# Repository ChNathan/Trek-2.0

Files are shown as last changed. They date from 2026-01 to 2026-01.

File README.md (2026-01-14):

# Trek-2.0
Project report and files for Oslo Met EPS project. We built a gait tracker for real time gait asymmetry over varying windows.

Included in this Repo Are:
- Trek EPS Report ( Which is covered in additional detail via this presentation https://docs.google.com/presentation/d/1eJzCRBbl3npr1pbE6kb9zn8NsA4ln3SlZraTO1EqVzs/edit?usp=sharing )
  - This report includes the project's purpose, progress, and future recommendations. We believe this project could be piloted in research studies with an additional project iteration.
- Firmware Code for Left and Right device, with and without SD Card
- User Interface Code
- Short user manual on setting up the device
- Autodesk Invetor CAD File for Case
- KiCad PCB Schematics, BOM, and additional design files

For any questions, comments, or concerns, please don't hestitate to contact us.
- Group 1, EPS Fall 2025


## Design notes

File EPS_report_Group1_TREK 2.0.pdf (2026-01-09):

## Oslo Metropolitan University

# TREK 2.0 :

# Bilateral Gait Monitoring System

image generated by AI
Completed by:
Chethan James Magnan,
Jeyapiriyan Thevaranjan,
Thomas Druillole,
Luke ten Klooster,
Michael Prediger,
Fall 2025

Mentored by:
Tom Muir
Tengel Aas Sandtrø

Supervised by:
Dr. Ali Muhrtagolu
Dr. Haroon Khan

European Project Semester

## Table of Contents

Table of Contents | 2
1. Introduction | 3
1.1. Project context | 3
1.2. Project objectives and relevance | 3
2. Scientific and Technical Background | 4
2.1. Fundamental concepts and key definitions | 4
2.2. Overview of existing methods and techniques | 5
2.3. Relevance to our project | 7
3. Review of Previous Work | 8
3.1. Previous Trek device | 8
3.2. Strengths of previous device | 9
3.3. Limitations | 9
3.4. Improvement and development strategy | 10
4. Project Management and Task Organization | 11
4.1. Mission Goals Scope (MGS) | 11
4.2. Project organization and planning | 12
4.3. Communication and collaboration | 13
5. System Architecture | 14
5.1. Hardware design and architecture | 14
5.2. System logical architecture | 15
5.2. Embedded firmware | 16
6. Implementation | 18
6.1. PCB design and hardware design | 18
6.2. Mechanical and 3D design | 20
6.2.1. Manufacturing methods | 20
6.2.2. Material selection | 21
6.2.2. 3D Design | 23
6.3. Signal processing and algorithm development | 25
6.3.1. Data acquisition | 25
6.3.2. Gait State Analysis | 26
6.3.3. Position estimations and stride length calculations | 31
6.4. Wireless communication | 33
6.4.1. Importance of wireless communication | 33
6.4.2. Choice of Bluetooth Low Energy (BLE) over Wi-Fi | 33
6.4.3. How Bluetooth Works in the System | 34
6.5. User Interface design and application development | 35
6.6. Integration and system validation | 37
7. Conclusion | 38
7.1. Project conclusions and key findings | 38
7.2. Skills acquired | 38
7.3. Reflections and overall experience | 39
8. References | 42
9. Appendix | 45

## 1. Introduction

## 1.1. Project context

As of 2010, there were 1.6 million people suffering from hip fractures, with 600,000 in Europe alone [1]. This number is expected to rise, with researchers predicting 6 million hip fractures annually by 2050 [2]. For the average person, the process seems straightforward: they go to the hospital, the surgery is successful, and all is well. However, about 40 to 60% of patients never fully regain their previous activity levels, experiencing declining mobility in daily life [2]. The cause is often musculoskeletal impairment following a hip fracture (sarcopenia) and an asymmetric gait, where steps do not align during walking [3]. Without frequent monitoring, this condition tends to progress, leading to slower walking, more frequent falls, and overall deterioration in quality of life. Because this decline occurs gradually and recovery feedback is delayed, many patients do not adhere to physical therapy or notice improvements. Improved monitoring and timely feedback from healthcare professionals could help these patients recover daily function more effectively [4].

## 1.2. Project objectives and relevance

For patients recovering from musculoskeletal impairments, measuring gait asymmetry is essential to track recovery and prevent physical deterioration before it becomes severe. The device must be easy to use, non-intrusive in daily life, and provide actionable information. Some solutions exist on the market but do not fully address our use case: supporting older adults in a physical therapy context to recover daily function. Some devices, like the MbientLab MMRL [5], are affordable but provide only raw sensor data, which can overwhelm non-technical users. Others, such as the Movella Xsens Awinda [6], are designed for highly specific clinical research applications, relying on a distributed sensor grid within a controlled environment and are prohibitively expensive, with purchase details handled directly via sales teams. Neither solution allows continuous, real-time gait analysis throughout the day.

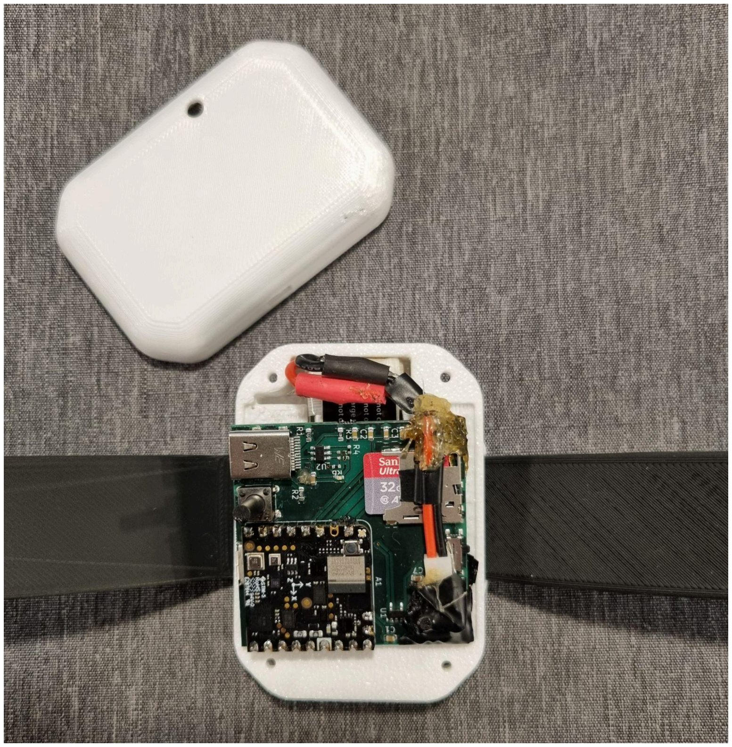
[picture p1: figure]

Figure 1.1 : Trek 2.0

Our project, Trek 2.0, is a compact wearable device designed to monitor walking patterns, building upon the prototype developed by the previous group. It enables patients and healthcare professionals to track gait asymmetry between the left and right legs in real time, providing insights to prevent long-term joint and muscle deterioration. The device is intended for use in physical therapy, offering continuous, easy-to-use, and non-intrusive gait monitoring to support recovery and improve daily function.

## 2. Scientific and Technical Background

This section starts by defining key concepts and providing an overview of the general research conducted in this area. This provides context, making it easier to understand the work of previous groups as well as our own development. More specific research and detailed studies can be found in their corresponding sections to maintain a clear and engaging flow.

## 2.1.Fundamental concepts and key definitions

General gait concepts :
Gait refers to the coordinated pattern of walking, describing how the legs and feet move during locomotion [7].

Gait assessment, also known as gait analysis, is the process of measuring and evaluating this walking pattern, typically using sensors such as inertial measurement units (IMUs) to quantify spatial, temporal, and symmetry-related parameters.

A gait cycle is defined as the interval between two consecutive heel strikes of the same foot, representing a complete sequence of movements that can be analyzed to extract relevant gait parameters. The different phases of the gait cycle are discussed in Section 6.3.2.

A gait event refers to a specific, identifiable moment within the gait cycle, such as a heel strike or toe-off. These events are key reference points for analyzing gait parameters, detecting asymmetries, and calculating stride and step characteristics.

Bilateral gait measurements refer to the simultaneous assessment of both legs, allowing for the evaluation of asymmetries and coordination between left and right limbs. These measurements are critical for understanding differences in gait patterns, detecting abnormalities, and improving the accuracy of gait analysis.

Stride length - definition and clinical relevance :

Figure 2.1 : Illustration of spatial parameters of gait

Stride length is a key gait parameter, defined as the distance covered by the foot during a single gait cycle. It is particularly relevant because it provides several advantages: it directly reflects walking efficiency and step consistency, offering a clear and interpretable measure of gait performance [8]. Furthermore, it can be tracked over time to assess changes or improvements in patients.

Stride length is sensitive to gait abnormalities and asymmetries, making it a valuable indicator for clinical assessment and rehabilitation. Studies conducted by Umeå University (Sweden), the University Clinical Centre of Kosovo, and St George’s University (UK) have shown that stride length is strongly associated with clinical outcomes such as disability and mortality [8]. According to Wang and Bhatt (University of Illinois at Chicago), individuals with a history of falls exhibited shorter stride lengths and significant asymmetries, highlighting the potential of stride length monitoring in fall prevention [9].

Stride length can also be compared across individuals by normalizing it to patient height (normalized stride length = stride length (cm) / height (cm)). For instance, Bytyçi and Henein (2021) reported that this normalized stride length was more accurate in predicting adverse clinical events, with a summary sensitivity of 65%, specificity of 72%, and overall accuracy of 75.5% [8].

Other gait parameters, including stride time and cycle time, are presented in Section 6.3, where their calculation and use in deriving additional gait metrics are detailed.

## 2.2. Overview of existing methods and techniques

Several studies and projects have explored the use of inertial measurement units (IMUs) for gait analysis. These works provide insights relevant to the development of wearable gait monitoring systems.

IMU-based gait assessment and bilateral coordination:

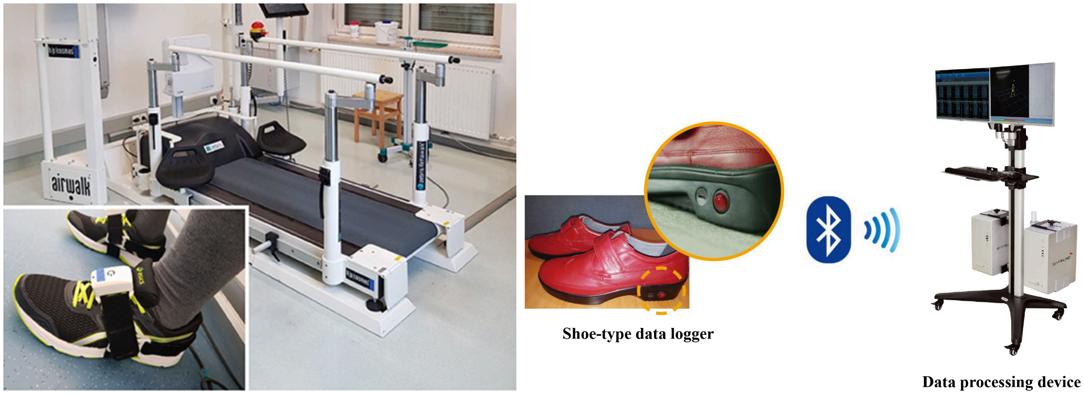
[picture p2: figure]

Figure 2.2 : Experimental setups from similar studies. Left: Laidig et al. (2021) – patient with foot-mounted IMUs and instrumented treadmill. Right: Han et al. (2019) – shoe-type IMU-based gait analysis system.

Laidig et al. (2021) [10] and Han et al. (2019) [11] demonstrated methods for assessing gait parameters using IMU sensors. Laidig et al. focused on foot-mounted sensors and calibration-free measurement of gait pattern, speed, rhythm, and step coordination, while Han et al. analyzed bilateral coordination and gait asymmetry with shoe-mounted sensors.

Sensor placement considerations:
Küderle et al. (2022) [12] and Panebianco et al. (2018) [13] investigated how sensor position affects measurement accuracy and reliability. Küderle et al. showed that different foot-mounted IMU placements strongly influence spatial parameter accuracy. Mean stride-length errors remained below 2 cm for most positions, while poorly located sensors, such as the heel, produced occasional single-stride errors up to ~60 cm, highlighting the importance of proper placement.

Figure 2.3 : Panebianco et al. (2018) – Sensor placement of the six shoe-mounted IMUs.

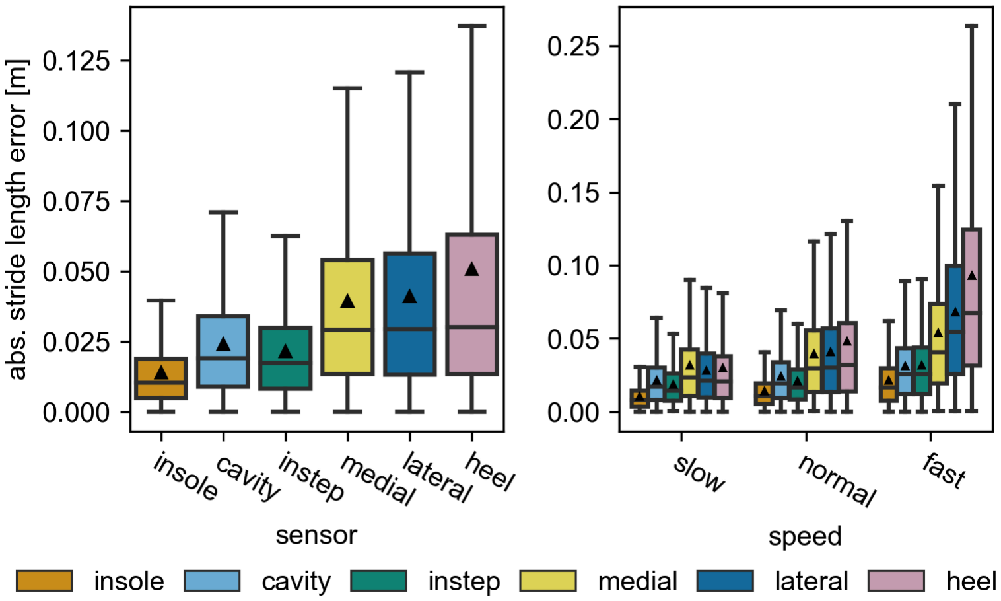
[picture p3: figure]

Figure 2.4 : Panebianco et al. (2018) – The absolute stride length error of each sensor position.

Panebianco et al. confirmed that sensor position significantly affects measurement repeatability, as shown in Figure 2.4, which illustrates the absolute stride-length error for each sensor position.

Gait event detection algorithms:
Panebianco et al. (2018) [13] evaluated 17 different algorithms for detecting gait events and estimating temporal gait parameters from IMU data. Their results showed that shank- and foot-based algorithms were more accurate and repeatable than lower-trunk-based approaches for detecting heel strikes and toe-offs. Angular velocity-based methods outperformed acceleration-based ones for these events, providing more reliable measurements.

Gait symmetry and coordination insights:
Błażkiewicz et al. (2014) [14] and Gimmon et al. (2018) [15] focused on gait symmetry and coordination. Błażkiewicz et al. compared methods for quantifying left-right differences, while Gimmon et al. studied changes in bilateral coordination with age, using the phase coordination index and gait asymmetry metrics. These works provide guidance for selecting symmetry metrics and interpreting variations across different populations.

## 2.3. Relevance to our project

The reviewed studies provide practical guidance for the development of our wearable gait monitoring system. Although Laidig et al. [10] and Han et al. [11] focused on foot- and shoe-mounted sensors, resulting in data different from ours, which uses lower-limb bracelets, these studies can serve as benchmarks to help interpret sensor signals and guide the measurement of gait parameters. They also provide a useful comparison for evaluating our final gait measurements.

Küderle et al. [12] and Panebianco et al. [13] emphasize the critical role of sensor placement and algorithm selection in ensuring measurement accuracy and repeatability. Insights from these studies support our choice of bracelet position. They can also guide algorithmic decisions for detecting gait events such as heel strikes and toe-offs.

Błażkiewicz et al. [14] and Gimmon et al. [15] are relevant to the project because it involves calculating differences between the left and right foot during walking. Błażkiewicz et al. provide guidance on selecting appropriate gait symmetry coefficients to quantify these differences, while Gimmon et al. show how bilateral coordination and gait symmetry vary with age. Understanding these variations helps interpret IMU sensor data accurately and assess gait differences across different populations.

## 3. Review of Previous Work

## 3.1. Previous Trek device

This project is a continuation of the previous Trek device, which presents both advantages and challenges for development.

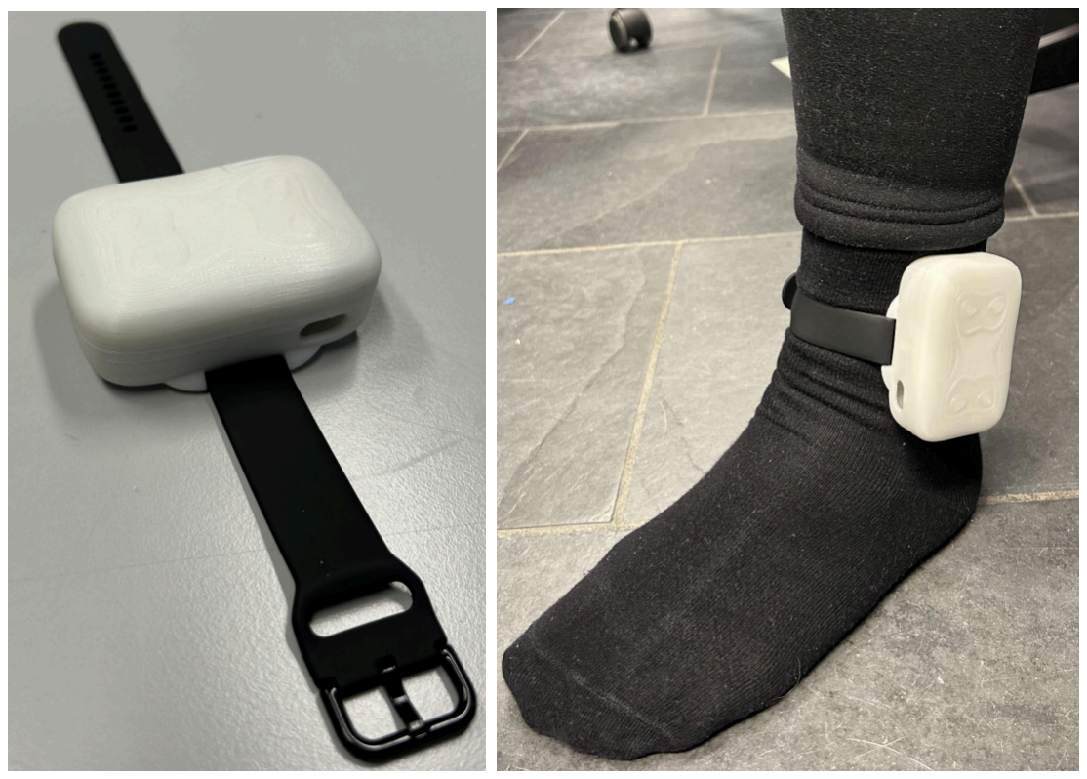
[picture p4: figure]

Figure 3.1 : Final prototype of the previous Trek device [16]

The previous Trek device is a proto-board with an IMU, (Inertial Measurement Unit), BLE transmitter and receiver (Bluetooth Low Energy), MicroSD Card, charging port, and power switch. This device takes accelerometer, gyroscope, and magnetometer data and saves this to a MicroSD card. The data can then be uploaded offline into an accompanying MATLAB script to calculate and generate a plot for the asymmetries between each leg.

Due to the existence of the previous product, we should be able to achieve more and better address the clients’ needs. We were starting with the basic circuitry, programming, mobile communication, and classification algorithms from the previous group. This would mean we could focus on optimization and expansion.

## 3.2. Strengths of previous device

The previous Trek device is the first step forward and accomplished what they set out to do -the device has a completed data path, the overall device physically worked. It is an end to end device, able to receive input from the Nicla, send these over the soldered wires for storage in a MicroSD card, and then output a useful gait asymmetry calculation with graph.

The main functional units were logically decided and purchased with off the shelf components to make the prototype work as predicted for the final use case. Finally, the previous team did use Github sharing how they had structured the arduino measurements and left a report detailing their project planning, execution, and suggestions for the future. This report was particularly useful as it allowed us to understand how they thought through their device, recreate the overall circuitry as photos covered how the device was wired, and have a very clear goal.

## 3.3.Limitations

There are three main areas for improvement based on the deliverables we received from the previous Trek group :
- Real-time asymmetry calibration was not possible. The device stored data on the SD card, and asymmetry values were computed offline in MATLAB. This prevented immediate feedback for the user.
- The device did not include any user interface. As a result, patients could not adjust their walking based on real-time feedback, and sharing data with a clinician was inconvenient. Without an interface, a medical professional could not easily compare changes in daily mobility, identify whether physical decline had slowed, or evaluate how gait evolved throughout the day.
- The device was too large. A more compact design was requested to improve usability and reduce manufacturing cost. Smaller devices are also better accepted by older adults. This is supported by recent long-term wearable research, which reports that “almost without exception, participants desired smaller and lighter wearables or expressed discontent about the size and weight of the device they were asked to wear in the study” [17].

## 3.4. Improvement and development strategy

The initial Trek device aims to solve this with a Goldilocks solution. The device is portable and customized to detect gait, but as we address in depth in the previous section, it is not real time, compact, nor have a ui device and therefore still in a prototype phase. Our further developments to the Trek device aims to make it a professional gait-tracking tool. We want it to be used for assisting in physical therapy, where professionals may monitor patient walking patterns in real time to prevent long-term joint and muscle damage.

With this objective, we defined three main development directions: creating a mobile interface, enabling real-time IMU data transmission, and reducing the device size and weight.

Achieving real-time communication requires redesigning the wireless data flow and reworking the embedded signal processing. To reduce energy consumption and extend battery life (thus allowing a smaller battery), most calculations must be performed directly on the embedded system, whereas the previous group relied on heavy MATLAB-based offline processing, which is not feasible on an embedded system.

We also plan to develop a custom circuit board, implement improved data batching to limit power draw, and design a new, thinner enclosure, so that we can reduce the overall footprint of the device and its size. This new design will also provide additional benefits in terms of manufacturing cost and component integration.

Figure 3.2 : Comparison image between TREK 2.0 (on the top) and TREK 1.0 (below)

## 4. Project Management and Task Organization

## 4.1. Mission Goals Scope (MGS)

Mission:
Trek is a clinical gait-tracking tool for physical therapy where professionals monitor patient walking patterns in real time to prevent long-term joint and muscle damage. Our mission is to enhance the system by improving user comfort, optimizing both hardware and software performance, and designing an intuitive interface that allows patients to monitor their gait in real time.

Goals:
Our main focus is completing the client’s request; make Trek real time, more compact, and have an improved user interface. For a functional TREK system capable of bilateral gait monitoring in real time we need system to turn on and send basic imu measurements via wireless communication

To make it lighter and compact (at least 20% smaller and weigh 20% less), we should have a custom circuit board design that is 20% smaller than previous as well as a case that’s 20% smaller by volume.

Finally, to improve the value of the user experience, we should make a mobile user interface that can assess and process the system in real time. This includes an adjustable window time scale to see a whole day of measurements.

Scopes:
Our main constraints are the previous group's work and the lack of clinical use case. We will not remake the project from the beginning and should reuse as much as possible from the previous group’s work, which means some of their decisions or technical debt must be considered.

This device is also not for a clinical use case at the moment. The intention is not for the product to be commercialized, nor diagnose medical problems, nor implement a user account management system. A commercialized product would need far more polishing and testing with user groups. To diagnose medical problems, we would want to work closer with medical professionals and need far more time and funding. Finally, as the group lacks a data specialist, the development of a digital database for the online interface will be omitted.

## 4.2. Project organization and planning

For the management part of our project, we wanted to ensure that the work is well organized and that every team member knows their responsibilities. Management therefore plays a key role in our team. During the research phase, we defined in detail the tasks required to complete the project. We grouped these tasks into five main study domains, each with clear objectives :
- Redesign circuit board: improve compactness, update components, and optimize embedded functionality.
- Redesign case: enhance ergonomics, adapt to the new materials and reduce size and weight.
- Sensor data processing: implement efficient algorithms for gait analysis in real-time.
- Wireless communication: enable real-time BLE data transfer between device and UI.
- User interface: develop a mobile interface for easy monitoring and feedback.

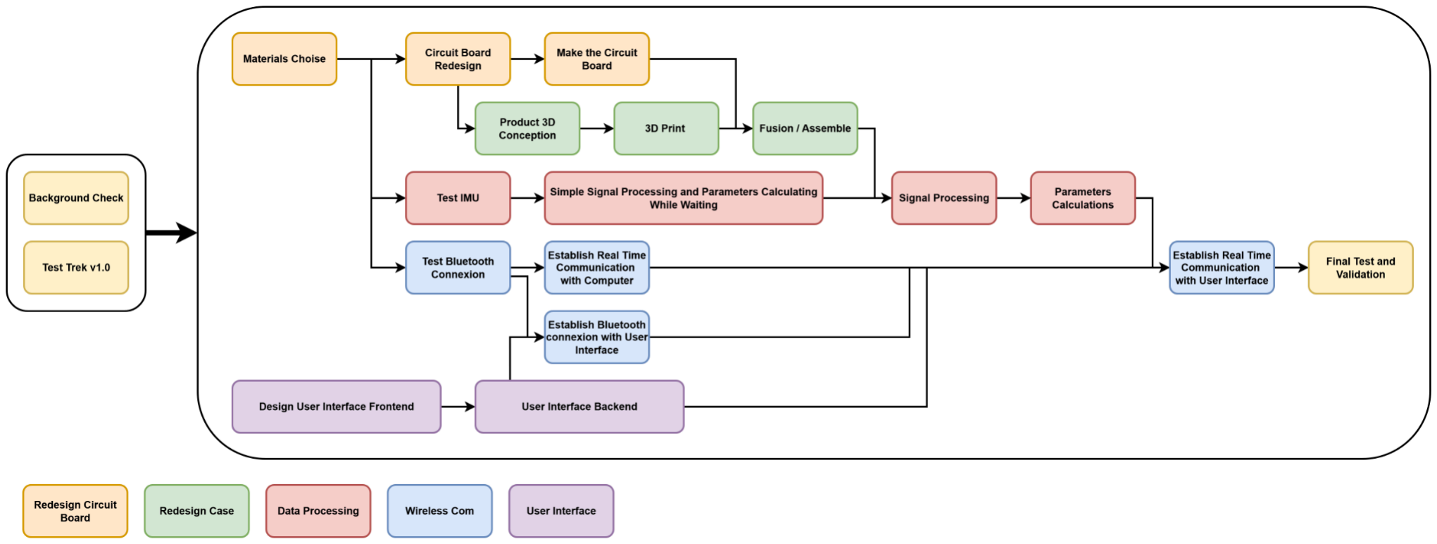
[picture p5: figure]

Figure 4.1 : simplification of the GANTT diagram

To manage the timeline, we created a detailed Gantt chart that helps us plan the various tasks, track progress, and identify deadlines (see appendix). We also prepared a simplified version of the Gantt chart (Figure 4.1) that groups the most important stages of our project. This version makes it easy to see the dependencies between stages.

To ensure the smooth progress of the project and clearly define each team member’s responsibilities, our team was organized around complementary areas of expertise. Each member took charge of specific aspects of the development, from mechanical design to software and embedded systems engineering, ensuring that all parts of the project were properly coordinated and progressed according to schedule.

- Chethan James Magnan – Computer Engineer: responsible for the circuit board redesign and communication with the supervisor.
- Jeyapiriyan Thevaranjan – Embedded Systems Engineer: focuses on embedded firmware development and manages the Gantt chart to keep the project on schedule.
- Thomas Druillole – Mechanical Engineer: handles Bluetooth real-time communication and backend support for the user interface.

- Luke ten Klooster – Mechanical Engineer: responsible for frontend and user experience.
- Michael Prediger – Mechanical Engineer: manages CAD design and prototyping of the case.

## 4.3. Communication and collaboration

To ensure effective communication and collaboration, our team relies on Microsoft Teams, WhatsApp, and GitHub. These tools allow us to share ideas quickly, centralize contributions, and maintain easy access to all project materials. GitHub is particularly useful for tracking changes in code and documentation, while Teams and WhatsApp facilitate fast discussions and coordination.

Although each team member has specific responsibilities as a team leader in their area, we work closely together rather than independently. Team leaders coordinate tasks, but all members are involved whenever needed, ensuring that progress is smooth and consistent across all areas.

Weekly meetings are held to review the work completed, discuss challenges, and plan tasks for the coming week. At the beginning of each meeting, members give a brief update on their progress. All discussions and task assignments are recorded in a shared document, which allows everyone to stay informed, follow the project’s progress, and adjust priorities if necessary.

This structured approach to communication and collaboration helps our team stay aligned, efficiently distribute the workload, and maintain high productivity throughout the project.

## 5. System Architecture

## 5.1. Hardware design and architecture

The systems hardware architecture organizes how power (via the battery and its USB C charging circuit ) will be supplied to the functional units of the Trek device ( the Arduino Nicla with its BLE and the MicroSD card ) as well as how the user will interact with the device ( the BLE on off button and the power switch ). This overall architecture is illustrated in the figure below. By optimizing the design for production, the cost is further reduced from approximately 130 EUR to 70 EUR. While the Arduino cost remains around 60 EUR, the price of the peripherals drops to roughly 15 EUR when manufactured in quantities of 1000.

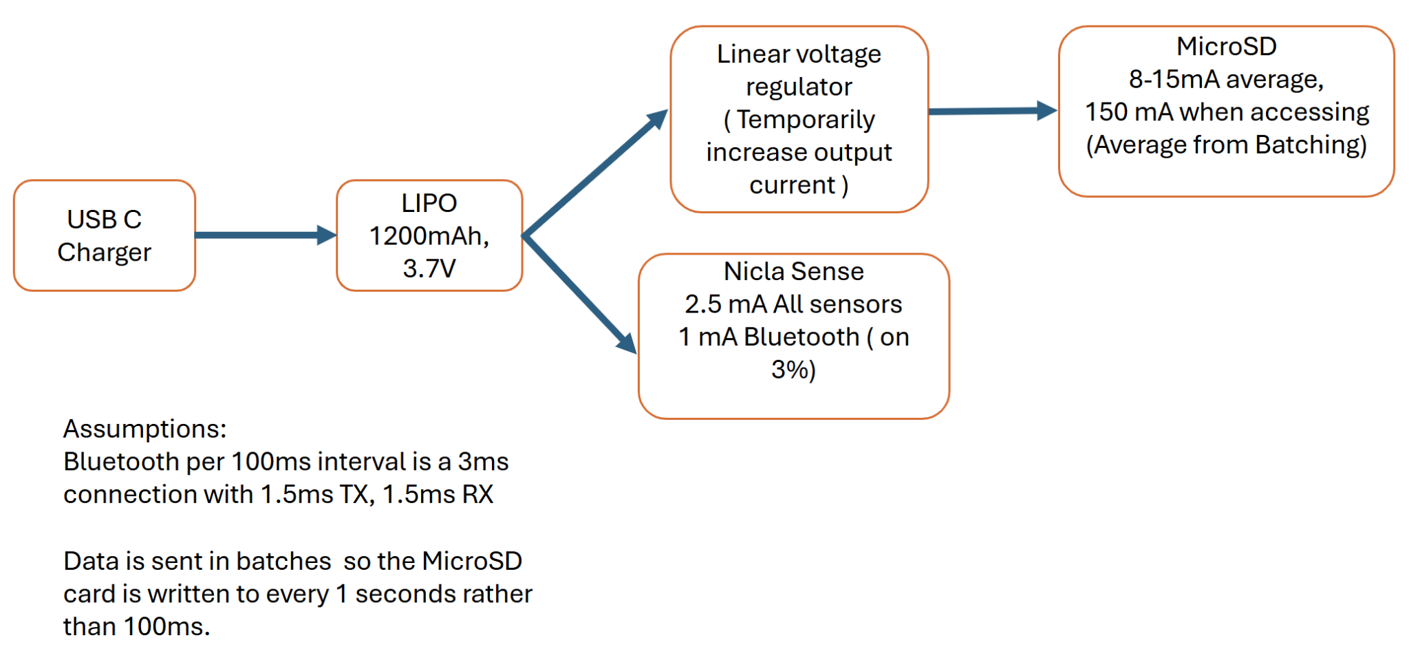
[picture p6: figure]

Figure 5.1 : Logical schema of the hardware architecture

The previous group used many of the same type of component and the overall structure is fairly similar. This was maintained to use the previous groups contributions as we agreed with their rationale - this component setup offers the main functionality such a device would require and met our clients requests.

The only major modifications to the circuit were; the BLE button, decreasing the distance between each component, and updating components that went out of stock. Decreasing the component distance makes the entire device more compact and leads to less noise. We achieved this through the design and outsourced manufacture of the Printed Circuit Board ( PCB ). Finally, some components were no longer offered by the suppliers and as such were updated with equivalent but more recent versions.

We also disagreed with the previous group's battery calculations and performed our own.By slightly reducing power consumption—primarily by decreasing the access interval to the MicroSD card (configured in the embedded firmware), we calculate that we can power the entire board per day on a minimum 3.7 V, 83 mAh, 307 mWH Lithium polymer (LiPo) battery.

For our design, we chose to use the 450 mAh 3.7v Utuav battery due to its thinner horizontal form and multiple day charge. This is again beneficial as it continues to make the design more compact for our end user when compared to previous 1200mAh LiPo. In terms of volume, the battery footprint decreases from 10.8 cm³ to 7.14 cm³ (a 34% reduction), and the surface area required inside the device decreases from 21.6 cm² to 10.2 cm² (a 53% reduction).

## 5.2. System logical architecture

Our TREK 2.0 system is built on a technical architecture that can be divided into three levels:

1) Data acquisition and real-time processing on the embedded board (Arduino Nicla Sense ME):
The embedded firmware continuously collects IMU data. These signals are processed with filtering methods to identify gait phases and spatial positions. Only the essential information—such as stride length and asymmetry—is extracted in order to reduce transmission load and optimize energy consumption.
2) Low-latency wireless transmission via Bluetooth Low Energy (BLE):
The processed data are sent to the interface through BLE in small, low-latency packets. In parallel, all raw and processed data are stored on the MicroSD card to ensure full backup even in case of disconnection, allowing the system to operate without requiring a permanent Bluetooth connection.
3) Real-time visualization and parameter display through the user interface:
The interface receives and decodes BLE packets in real time, updates its graphs, and recalculates parameters over the time window selected by the user. This enables continuous and instantaneous visualization of gait behaviour and asymmetry between both legs. The user can choose between a minimal mode (real-time essential information: stride length, asymmetry) or a debug mode (detailed analysis, not real-time).

Figure 5.3 : Logical schema of our device architecture

## 5.2. Embedded firmware

The Nicla Sense ME embedded in the bracelet must operate fully autonomously to ensure continuous gait monitoring under all conditions. For this reason, the system requires a robust embedded firmware capable of handling all operational scenarios without external intervention.

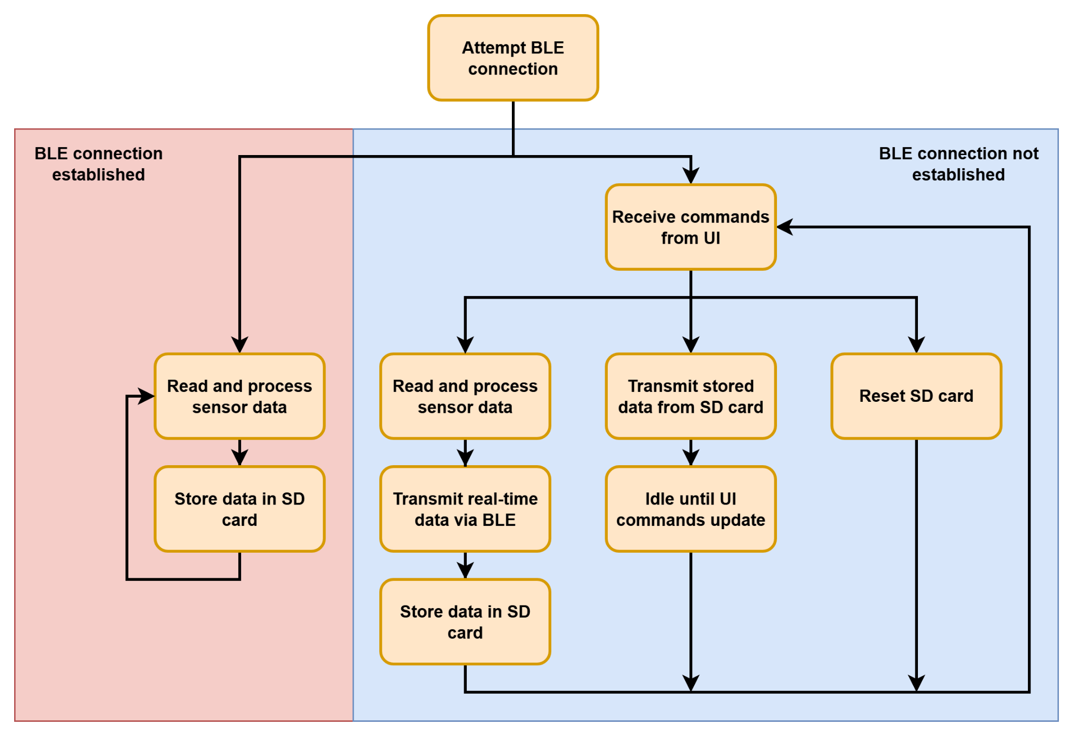
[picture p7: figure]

Figure 5.2 : embedded firmware architecture overview

Real-time communication is one of the major improvements compared to the previous group’s work. At startup, the firmware attempts to establish a Bluetooth connection with the user interface (UI) during a 20-second initialization window. Two operational modes are then possible:

- If the Bluetooth connection is not established within the allotted time : the system switches to standalone mode, where gait measurements are continuously acquired and stored locally on the MicroSD card.
- If the Bluetooth connection is successfully established : the firmware enters real-time streaming mode. Sensor data are transmitted live to the UI while simultaneously being logged on the MicroSD card to ensure that all data are saved.

In this mode, the board can also receive configurations from the UI, such as the selected operating ui-mode (section 6.5) and the data transmission frequency (section 6.5), allowing the user to adapt system behavior in real time.

Additionally, when the device receives the command to enter debug mode and the onboard button is pressed, all previously stored MicroSD-card data are transferred to the UI.To return to streaming mode, the ui-mode must be switched and the button pressed again.

This dual-mode architecture guarantees continuous gait data acquisition regardless of connectivity conditions.

## 6. Implementation

## 6.1. PCB design and hardware design

For the Printed Circuit Board (PCB) design and function, we used the existing circuit. Time constraints and Oslo Met's electronics lab dictated the scale and type of PCB. We did surface-mount full assembly with Eurocircuits, so the main focus was designing the PCBs and validating or modifying them based on tests.

The design process proceeded relatively smoothly, taking a few weeks to find the original parts used by the previous group. We chose to maintain the same PCB and general components to prevent any coding or peripheral communication errors. As most of our initial development was done using the Arduino Nicla given by the previous group, we kept using this as our main CPU / processing unit.

The PCB functions as a socket connecting the Arduino Nicla sense me and attaches the battery charger, battery pack, MicroSD card with reader, and two switches – a push button for choosing to access Bluetooth as a power saving feature and an SPDT power switch. The designs were done in Kicad, and some sampling from online schematics from Soldered Electronics was done (both are open source and available for our use case). The schematics, PCB layout, and 3D visualizations are included in the appendix.

Figure 6.1 : CAD of the PCB board

These designs were then reviewed and submitted to Eurocircuits for manufacture. After receiving 5 PCBs, a multimeter and power supply were used to confirm that there were no shorts in the circuit, that each functional unit worked appropriately, and that the PCB could receive and charge power from the lithium ion battery.

Some minor modifications were necessary: the button was rotated, the power connector needed to be modified to accommodate our battery’s connector, and a resistor needed to be removed that shorted the linear voltage converter for the USB-C charger. Once these modifications were complete, the PCB met the needs of the project in terms of battery life, support for real-time functionality, and size reduction.

The overall battery life matched the theoretical calculations. Real-time access to the MicroSD card is supported, and Bluetooth communication remains fully functional. Finally, the PCB footprint was reduced from 21.46 cm² to 17.22 cm², corresponding to a 19.8% reduction.

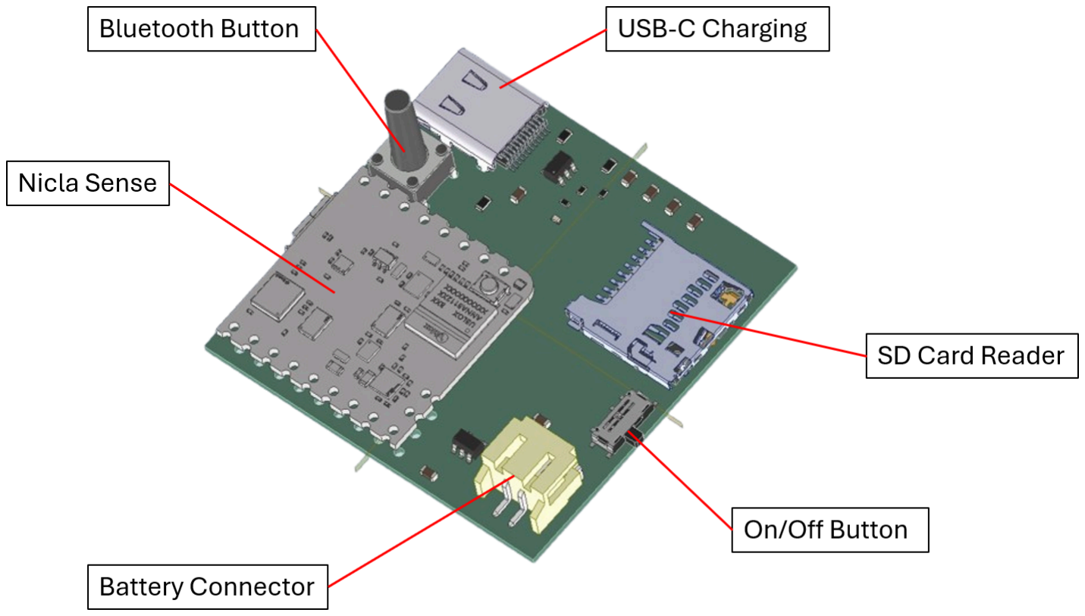
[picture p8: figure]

Figure 6.2 : CAD of the PCB with component labels

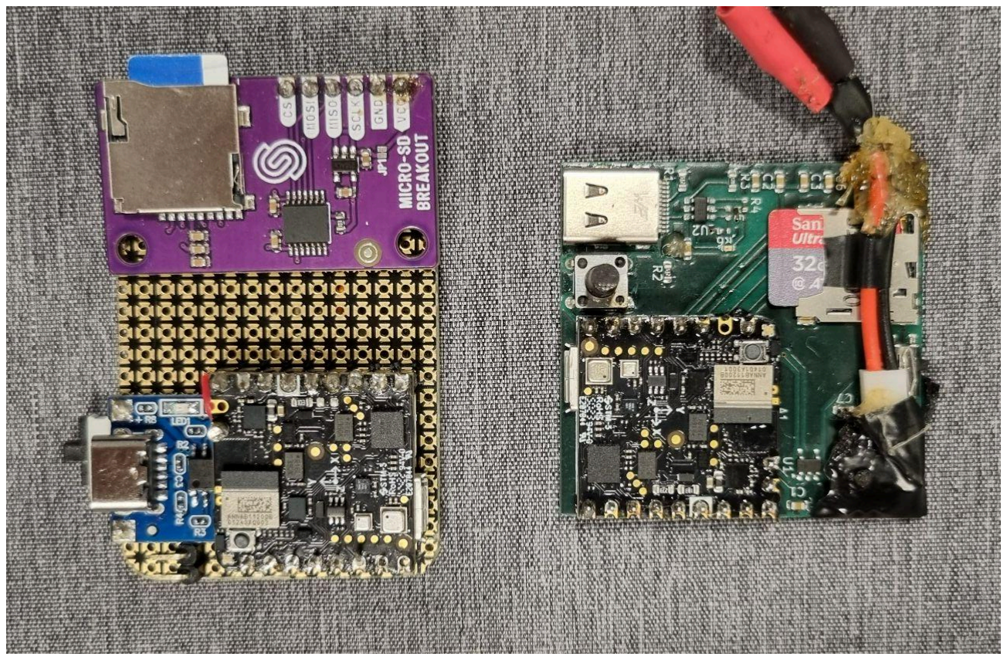
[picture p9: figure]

Figure 6.3 : Previous board (left) compared to our PCB (right)

## 6.2. Mechanical and 3D design

This part of the report outlines the development process of the 3D model and the manufacturing of the prototypes. The focus of this work was the design of a new case that securely positions all internal components while improving overall usability. Compared to the device created by the previous group, our prototype aims to offer enhanced wearing comfort. The goal was to create a compact and lightweight design that provides mechanical stability.

6.2.1. Manufacturing methods
Before selecting the materials, suitable manufacturing methods must be determined.

Conventional Manufacturing :

Figure 6.4 :Conventional manufacturing schematically

Conventional manufacturing processes are traditional methods that primarily involve machining, forming, or separating techniques in which material is mechanically processed, such as turning, milling, drilling, or grinding. As shown in the figure, you can see what a milling process looks like: you start with a solid block of material and then remove material until the final part is created.
For manufacturing our prototype, this method is unsuitable, as the geometry is very challenging to produce with it.

Additive Manufacturing :

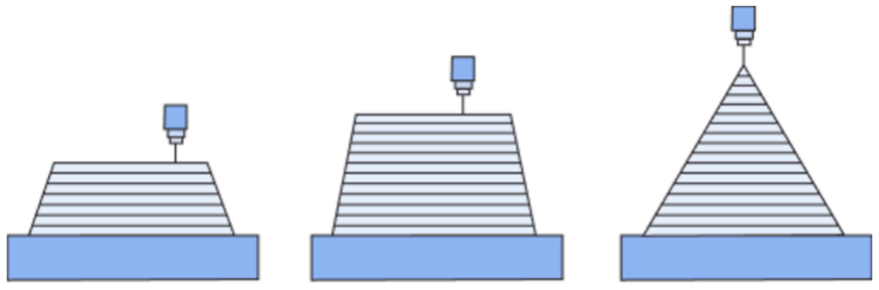
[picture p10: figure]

Figure 6.5: Additive manufacturing schematically

Additive manufacturing describes manufacturing processes in which components are built up layer by layer. Instead of removing material, as in conventional methods, material is added in a controlled manner, creating entirely new design possibilities. Figure 6.5 shows schematically how a component is built additively in layers.

Additive manufacturing is particularly suitable for prototyping, as it offers greater geometric freedom compared to conventional methods. Moreover, it allows components to be produced directly from CAD models without the need for additional tooling or extra costs. For this reason, we decided to use additive manufacturing processes, specifically filament-based 3D printing (FDM).

6.2.2. Material selection
After choosing the manufacturing method, we can choose the materials. Since our project is currently at the prototype stage, materials suitable for additive manufacturing are being considered. For series production, more cost-effective materials and processes such as injection moulding can be used to enable efficient manufacturing at larger volumes.

Case :
Thermoplastic polymers are particularly suitable, as they are lightweight, cost-efficient, and compatible with additive manufacturing methods such as Fused Deposition Modeling (FDM). Common materials include PLA (Polylactic Acid), ABS (Acrylonitrile Butadiene Styrene), and PETG (Polyethylene Terephthalate Glycol-modified).

PLA is easy to process and environmentally friendly but tends to be brittle and less heat-resistant. Whereas, ABS offers improved mechanical toughness and thermal stability but requires controlled printing conditions due to its tendency to warp. But we decided to use PETG which combines the advantages of both materials. It provides good impact resistance, higher chemical stability than PLA, and is relatively easy to print, making it a suitable material for functional prototypes.

The two tables below show the required printing settings and the mechanical properties of the filament types in comparison.

Figure 6.6 : printing settings required for PLA, ABS and PETG [19]

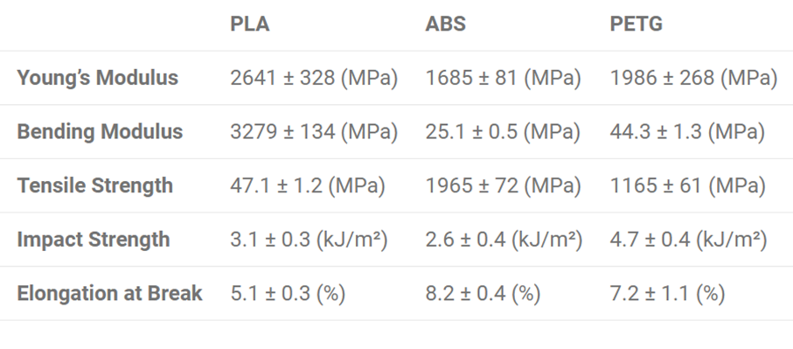
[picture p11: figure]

Figure 6.7 : Comparison of material properties for PLA, ABS, and PETG [19]

Strap :
The strap used to secure the device around the ankle must combine flexibility, mechanical strength, skin compatibility. For the functional prototype in this project, the strap is produced using 3D printing with TPU (thermoplastic polyurethane), because the material combines suitability for elastic structures, advantageous mechanical properties, and cost-effectiveness.

6.2.2. 3D Design
The mechanical components of the prototype were designed using Autodesk Inventor. The following figures illustrate the final 3D design.

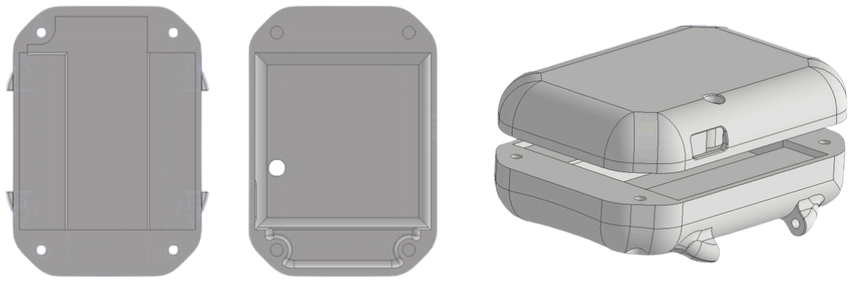
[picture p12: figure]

Figure 6.8 : left: Top view top and button case parts, right: Opened view of the case parts

In the final version of the prototype, the battery is clamped into the bottom of the case. The electronics are placed on the battery and held in position by the top part of the case. The top part features a hole for the Bluetooth button, while one side has a cutout for the On/Off button and the opposite side provides an opening for the USB-C charging port. The two parts of the case are fastened together at all four corners with screws.

Figure 6.9 : top view of bottom case part

The underside of the case that rests against the leg is slightly curved to better fit the shape of the leg. All four corners of the case are chamfered, and all external edges are rounded. This design not only makes the component more comfortable to wear and handle, but also improves its stability, as chamfers and radii help distribute forces more evenly.

The case also includes attachments for the strap at the bottom. The strap is designed similarly to a watch strap. One side features a pin buckle, while the other side has the holes for fastening.

Figure 6.10 : Assembled CAD model of case, battery and PCB board

The developed prototype successfully improves upon the device created by the previous project group in terms of size, weight, and cost efficiency. The redesigned case reduces the overall volume from 933,8 cm² to 718 cm², corresponding to a decrease of approximately 23,12%. This more compact geometry not only enhances wearing comfort but also minimizes interference with natural ankle movement.

Similarly, the total weight was lowered from 105,8 g to 75,1 g, representing a reduction of around 29%. This is particularly relevant for continuous gait analysis, where every additional gram affects fatigue and user acceptance.

Overall, these improvements make the device significantly more comfortable, lightweight, and user-friendly, contributing to better long-term wearability and a more reliable data collection experience.

## 6.3. Signal processing and algorithm development

6.3.1. Data acquisition

Similar to the previous group, data collection is performed using the Nicla Sense ME board through comparable methods. This board integrates the BHI260AP [20], a 6-axis IMU (3-axis accelerometer and 3-axis gyroscope). The sensor operates at 1.8 V with a standby current of 8 µA, resulting in a very low power consumption of 0.014 mW in standby mode [21]. In this mode, the sensor remains active and capable of basic measurements while consuming minimal power, enabling the board to operate autonomously without a constant connection to a computer. The device also includes a smart AI sensor capable of on-board motion detection and sensor data fusion, which is discussed in a later section.

Different types of data can be collected from the Nicla Sense ME board [22]. For the gyroscope, SENSOR_ID_GYRO is used because it provides calibrated measurements with offsets corrected, ensuring accurate angular velocity readings. Similarly, accelerometer data could be retrieved from the corrected accelerometer channel SENSOR_ID_ACC, but this still includes the effect of gravity. For this reason, SENSOR_ID_LACC is preferred, as it delivers linear acceleration with the gravitational component removed and internal filtering applied, providing cleaner signals that better represent actual motion.

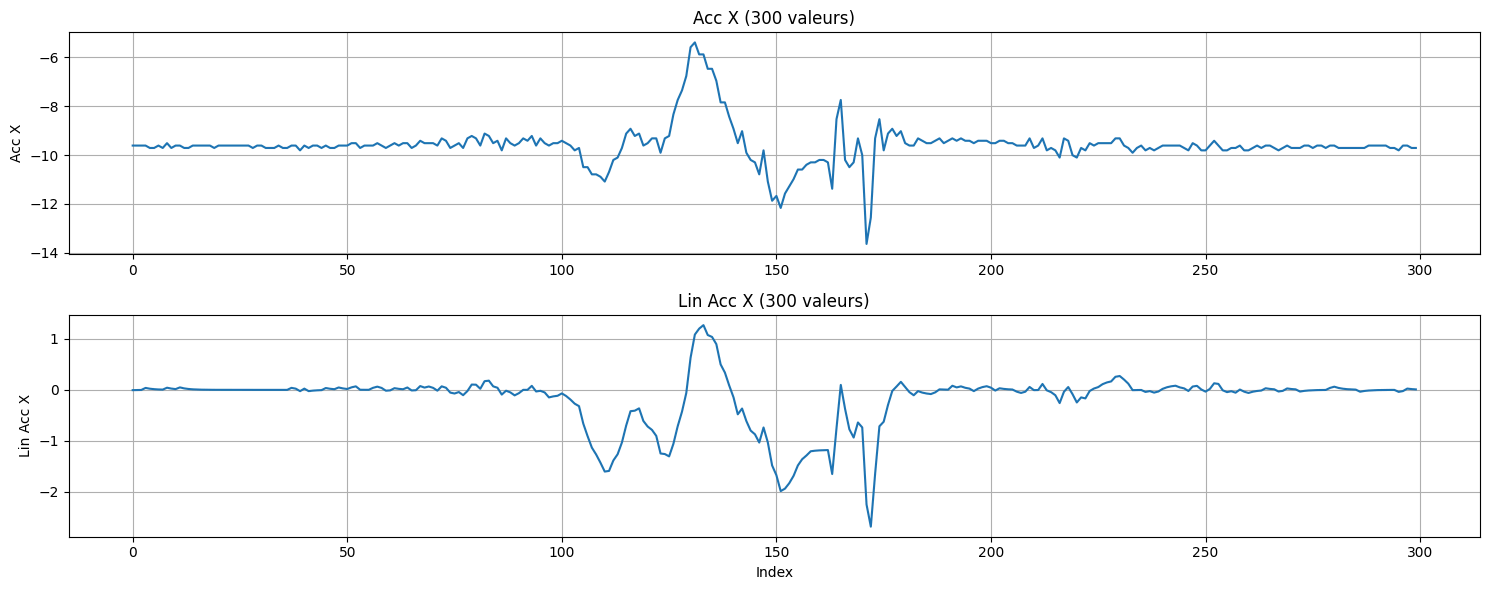
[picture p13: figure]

Figure 6.11 : comparison of raw and linear x-axis acceleration showing gravity removal and low-frequency noise reduction

6.3.2. Gait State Analysis

Detection of immobility :
It is important to detect immobility at two levels. First, identifying when the user is completely stationary helps avoid unnecessary calculations. Second, detecting when the foot remains still between steps allows variables such as velocity and position estimates to be reset for each step. This prevents error accumulation over time and improves the accuracy of step-by-step motion analysis. The following figure illustrates how such resets can significantly improve data quality.

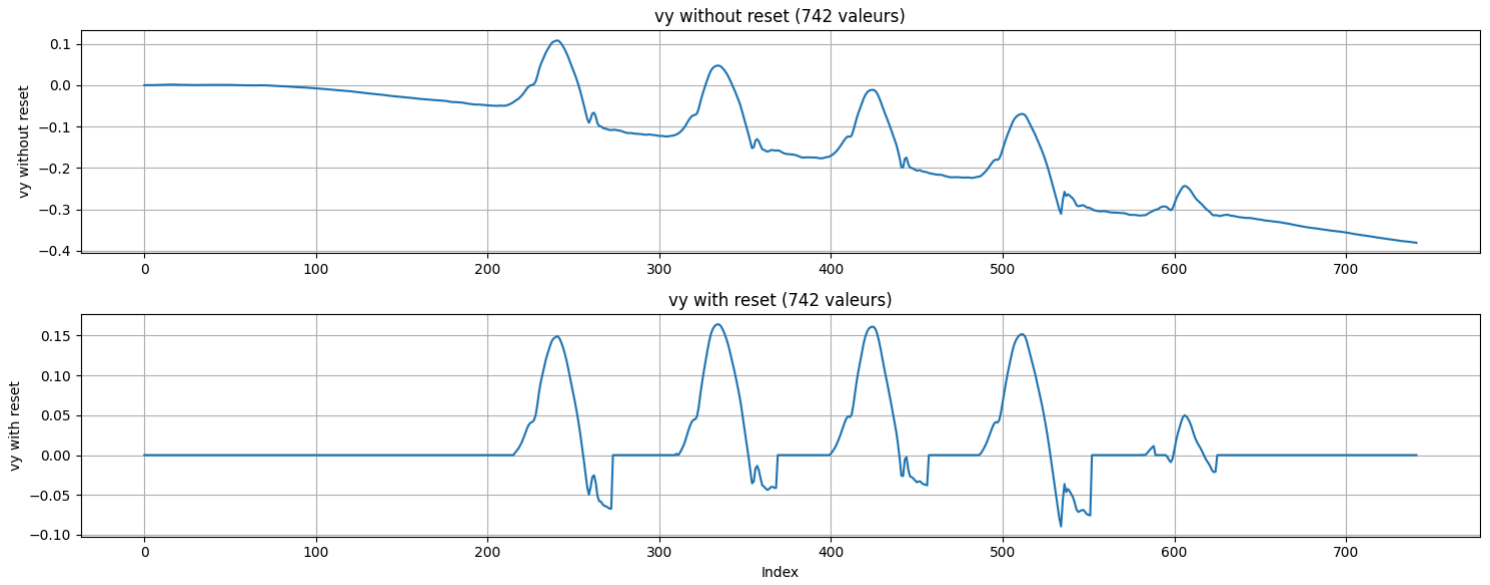
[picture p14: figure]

Figure 6.12: Effect of step-by-step reset on velocity measurements

To detect foot immobility, the previous group used a simple calculation based on the magnitude of the three-axis accelerations :

Since they worked with raw accelerometer values (SENSOR_ID_ACC), the magnitude remains around 1 g (accMagnitudeNorm) when stationary, reflecting the constant gravitational acceleration. Immobility was thus detected using the condition : fabs(accMagnitude - accMagnitudeNorm) < accThresholdTolerance

Figure 6.13 : Foot immobility detection from the previous group – acceleration magnitude (pink) and reset activation (blue)

However, this approach has several limitations. As shown in the figure, even when the board is in motion, the acceleration magnitude can easily pass through the immobility zone near 1
g. This can cause the reset activation to occur during walking, potentially introducing errors in velocity and position calculations.

To improve immobility detection, the board is considered stationary only when the acceleration magnitude remains within the immobility zone for a prolonged period. Instead of using the magnitude directly, its derivative is computed:
float deriv = (accMagnitude - prev_acc) / DeltaTime;

A smoothed derivative is then obtained using an exponential moving average (EMA) over the last two derivatives:
float ema_deriv = alpha_deriv * deriv + (1 - alpha_deriv) * prev_ema_deriv;

The EMA provides a weighted average of past values, with weights decreasing exponentially for older data. The parameter alpha_deriv controls the responsiveness:
small alpha → strong smoothing, past values dominate
large alpha → weak smoothing, recent changes dominate

An alpha of 0.3 was chosen, giving 70% weight to the previous EMA, so the smoothed derivative reacts slowly to rapid variations. The new derivative contributes only 30%, reducing instantaneous peaks and noise. This approach allows ignoring rapid fluctuations caused by accelerometer noise while still detecting actual movement. A moderate alpha (0.2–0.3) balances responsiveness and smoothing.

In addition to the derivative, the acceleration magnitude was also smoothed using an alpha of 0.2, allowing a dual condition for immobility detection:

bool near_ref = fabs(ema_acc - acc_ref) < tol_acc; bool slow = fabs(ema_deriv) < deriv_tol;
if (near_ref && slow && !was_still) {
//reset
}

Thus, the foot is considered immobile when the magnitude is close to 1g and the derivative is near zero. However, since linear acceleration is used directly, the reference magnitude is set to 0. During movement, the magnitude rarely approaches the immobility zone, but to ensure robustness, the derivative check is retained as an additional verification.

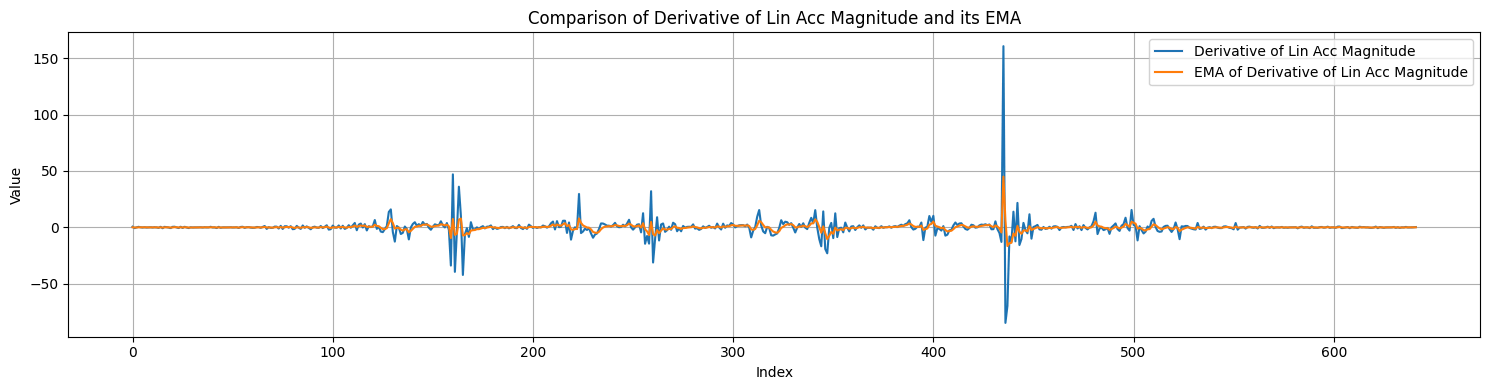
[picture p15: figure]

Figure 6.14: Comparison of linear acceleration magnitude and its derivative with their smoothed EMAs

Figure 6.15 : Linear x-acceleration and foot immobility detection

Figure 6.14 illustrates the effect of EMA smoothing and shows how acquisition errors and abrupt fluctuations can be effectively removed. Figure 6.15 demonstrates the performance of the immobility detection algorithm: the signal switches to true (1) when the board is stationary and to false (0) when it is in motion.

Gait state identification during walking :
To calculate accurate gait measurements and estimate positions, it is necessary to understand the structure of human walking. In practice, a complete gait cycle is defined as the interval between two consecutive heel strikes of the same foot, and it is commonly divided into two main phases: the stance phase and the swing phase.

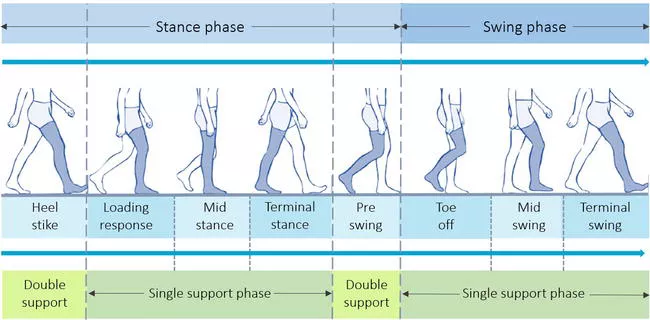
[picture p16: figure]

Figure 6.16: Subdivisions of the stance and swing phases of the gait cycle

The stance phase corresponds to the period during which the studied foot remains in contact with the ground. It includes both the single-support period, when the opposite foot is in swing, and the double-support period, when both feet support the body. This phase typically represents around 60% of the gait cycle [23][24].

The swing phase corresponds to the period during which the studied foot is moving forward. It accounts for approximately 40% of the gait cycle [23][24]. The swing phase begins with toe-off, continues through mid-swing, and ends at terminal swing, when heel strike occurs and the foot contacts the ground again.
Accurate stride length estimation relies primarily on the swing phase. In the collected sensor data, it is therefore essential to identify this phase in real time.

To identify the swing phase, we used the gyroscope data. Indeed, unlike other similar projects that placed the IMU on the foot (inside the shoe or on the bridge), our device is positioned on the ankle. As a result, its orientation varies in a characteristic way at each stage of the gait cycle, making the phases easier to recognize [13].

The following figure shows the similarity between the evolution of the inclination angle (unitless) and the different stages of the gait cycle of the corresponding foot. During the stance phase, the angle decreases and passes through 0°, which corresponds to the mid-stance (orange + yellow). Then, during the swing phase, it increases rapidly to reach the initial orientation (green). The decrease at the beginning of this phase corresponds to the toe-off stage, during which the foot must move backward to lift off from the ground.

To facilitate phase identification, the angle was measured with brief pauses between stages, corresponding to the constant, uncolored sections. In normal walking, these pauses would not appear, and the transitions between colored regions would be continuous.

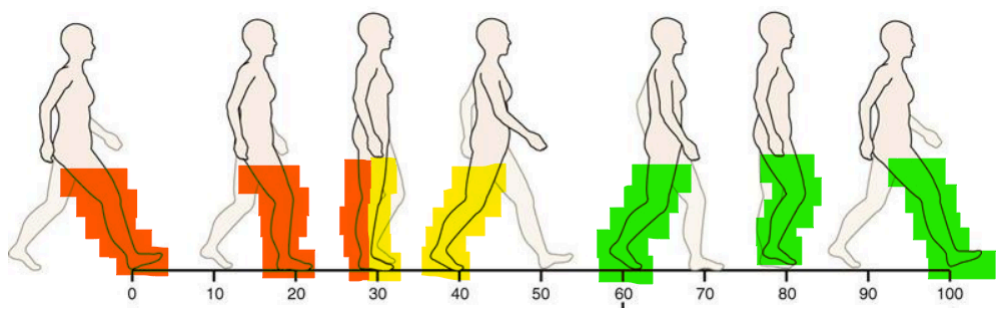
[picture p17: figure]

Figure 6.17 : Foot positions during the gait cycle with corresponding ankle inclination angle evolution

Thus, the swing phase can now be easily identified, allowing data to be processed specifically for this phase.

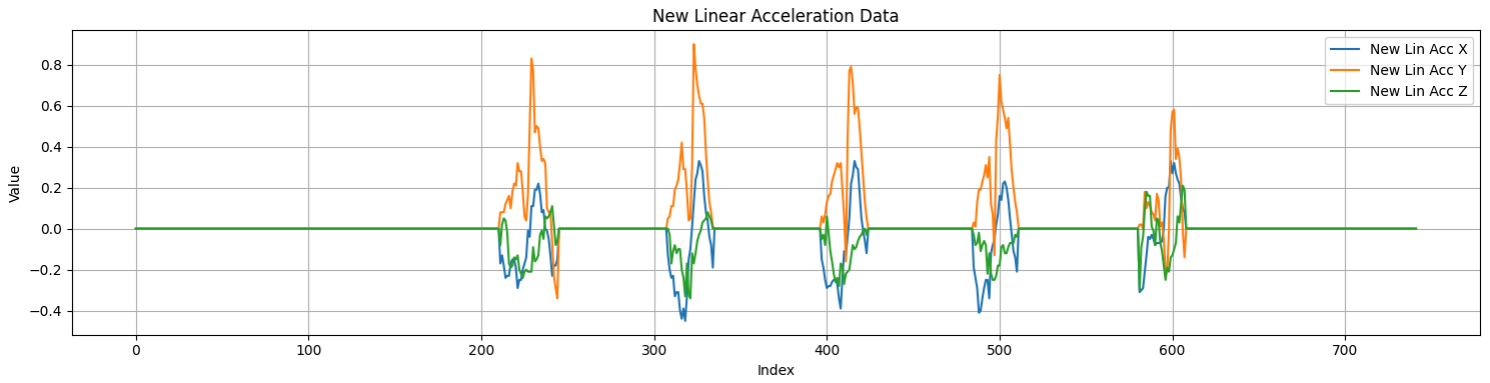
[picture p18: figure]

Figure 6.18 : Three-axis linear acceleration isolated to swing phase (zeroed during stance)

6.3.3. Position estimations and stride length calculations

Once the data have been separated, it becomes easier to integrate the accelerations into velocity and then into position. This segmentation allows computations to be performed over shorter time intervals, which significantly reduces error accumulation and mitigates issues associated with double integration.

Compared to simple Euler integration, we used trapezoidal integration :
Euler: vn+1 = vn + an * Δt:
Trapezoidal: vn+1 = vn + (an+1 + an)/2 * Δt

This method updates the velocity based on the average acceleration over a small time interval, providing a more accurate estimate than the simple Euler method while remaining sufficiently straightforward for implementation on an embedded system.

Figure 6.19 : Estimated velocity components along the x-axis (vx) and y-axis (vy)

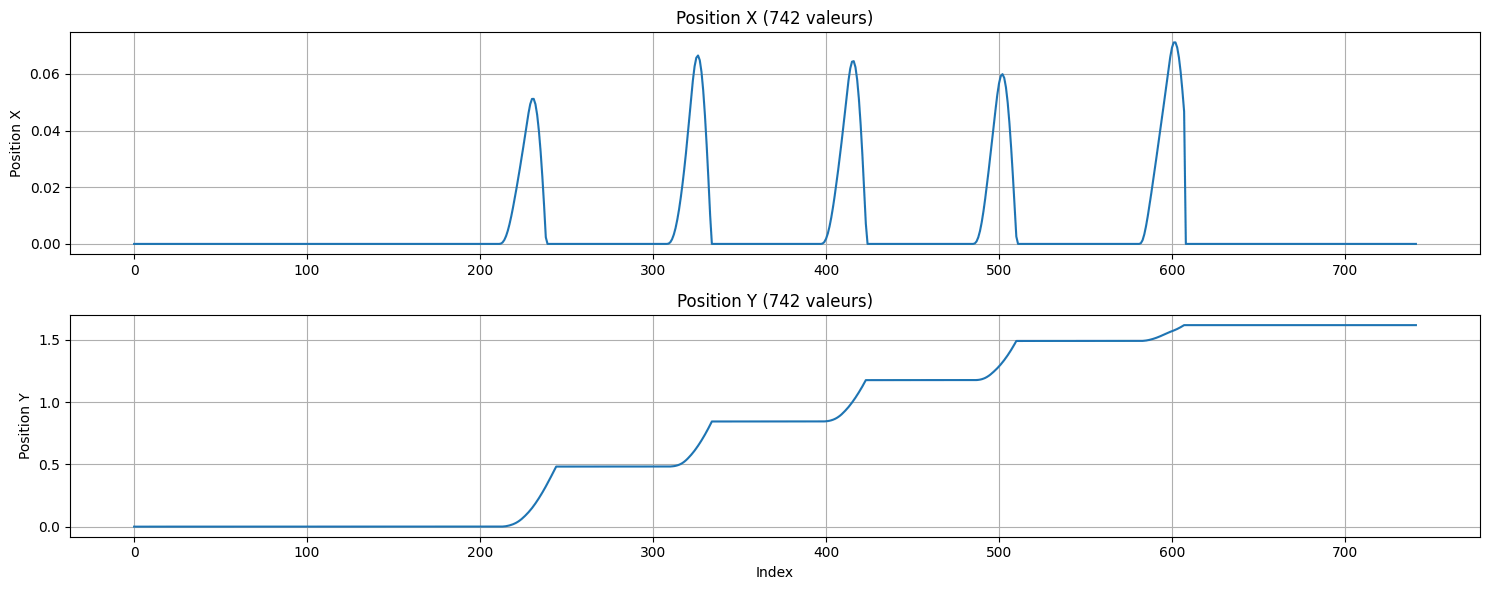
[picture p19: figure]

Figure 6.20 : Estimated position components along the x-axis (px) and y-axis (py)

To obtain an accurate position estimation, we adjusted the reference frame so that the x-axis points upward instead of toward the ground, while the y-axis represents the walking direction. The resulting trajectory shows a stair-step pattern, where the stride length corresponds to the magnitude of displacement at each step.

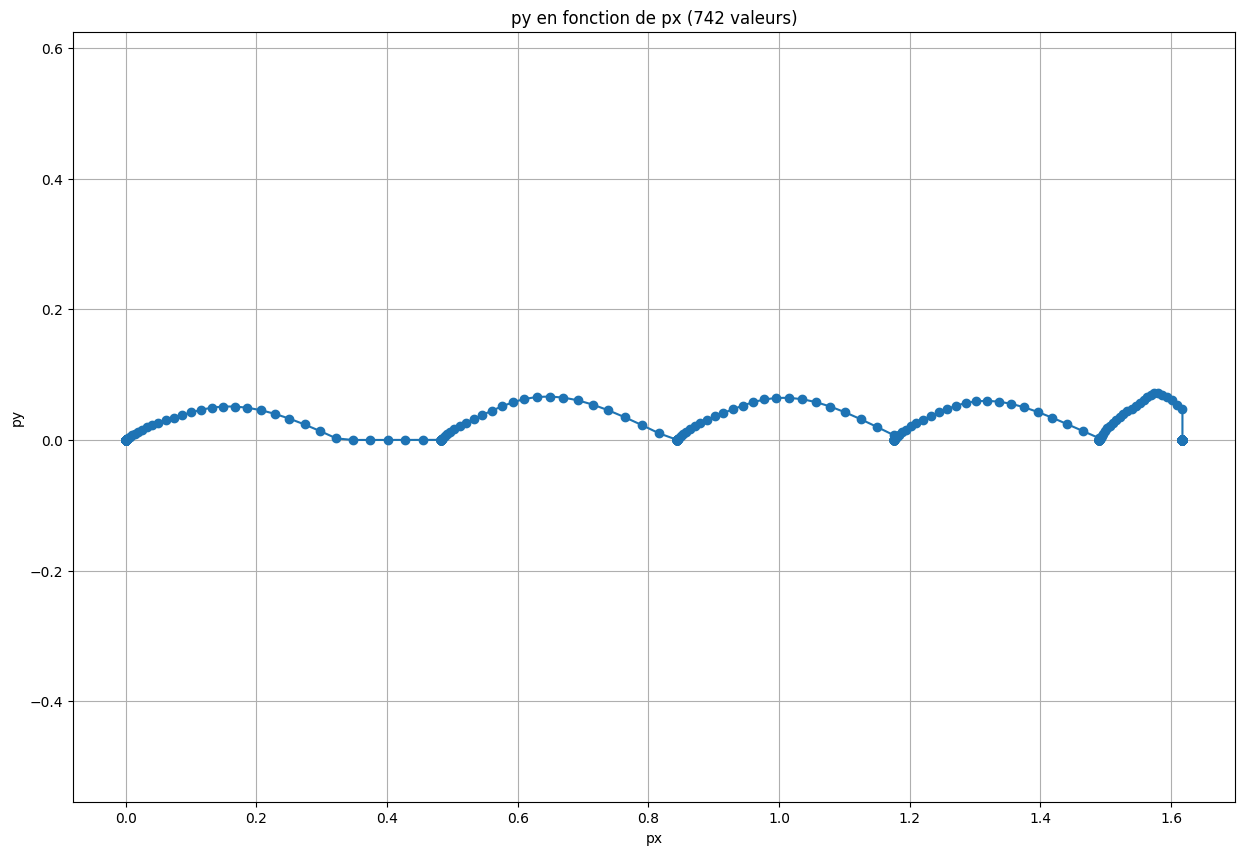
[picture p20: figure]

Figure 6.21 : 2D walking trajectory

As we are calculating the stride length asymmetry between the left and right legs, no scaling was applied to conserve processor power. The following diagram shows the results obtained in a realistic scenario where the subject walked for five minutes.

Figure 6.22 : Results from the 5-minute walking test

From this data we can calculate the stride length and send them via BLE to UI.

## 6.4. Wireless communication

6.4.1. Importance of wireless communication

Wireless communication is one of the main aspect of our TREK 2.0 bracelet, as it enables data transmission from the embedded sensors to an external device without any cables. This is crucial for our wearable gait analysis device: the absence of cables enhances comfort, freedom of movement, and safety for the user.

In practice, data from the IMU are transmitted after processing in real time to our web interface (on the computer or the phone). This allows instant analysis, live visualisation, and facilitates clinical or experimental monitoring.

Wireless communication therefore plays a key role in ensuring portability, ease of use, and responsiveness, while contributing to the compact and lightweight design of our TREK 2.0 system.

6.4.2. Choice of Bluetooth Low Energy (BLE) over Wi-Fi

We had two wireless options during this project: Wi-Fi and Bluetooth Low Energy (BLE). While Wi-Fi provides high bandwidth (typically 50–150 Mbit/s) and long range (up to 50–100 m indoors), it also demands high power consumption, often 150–250 mA during transmission, and requires a network infrastructure (router or access point), along with complex configuration steps (IP addressing, authentication, credentials, etc.). These factors are incompatible with the TREK 2.0 design goals of simplicity and autonomy.

BLE, on the other hand, was designed for low-power and short-range communication in wearables and connected devices. Its main advantages include:
- Very low power consumption: typical values range from 5–15 mA during transmission and only 1–10 µA in deep sleep, allowing extremely long battery life.
- Direct device-to-device connection, without requiring any Wi-Fi infrastructure. BLE pairing and data exchange occur directly via GATT services.
- Low latency, suitable for real-time sensor data: wake-up times around 6 ms, and effective communication latency often below 20–30 ms.
- Moderate data rate, fully sufficient for sensor information: BLE V4.x supports up to 1 Mbit/s, and BLE V5.x up to 2 Mbit/s.
- Short-range but stable communication, typically 10–30 m, and up to 100 m in BLE 5 Long Range modes.
- Broad compatibility with modern systems on native support such as Microsoft, Android or IOS

So we choose BLE because it offers the most appropriate solution: a lightweight, reliable, and energy-efficient communication method perfectly aligned with our bracelet’s requirement

6.4.3. How Bluetooth Works in the System

Bluetooth communication in TREK 2.0 follows the Client/Server model defined by the BLE protocol.

On the bracelet (BLE server)
The embedded board acts as a BLE server. It advertises a service, identified by a unique UUID, containing several characteristics that hold sensor data such as accelerometer or gyrometer that we will process to obtain the positions... The server automatically sends updates to connected clients via BLE notifications.

On the computer/phone (BLE client)
The computer or web browser acts as a BLE client. Unlike headphones or keyboards, the TREK 2.0 bracelet does not appear in the operating system’s Bluetooth list, because those menus only detect classic Bluetooth devices (using SPP, HID, or A2DP profiles).

So BLE has to use a distinct GATT (Generic Attribute Profile) structure, designed for structured and event-driven data exchange.

As a result, the connection cannot be established through standard Bluetooth pairing. Instead, it must go through software capable of communicating over GATT. That is why, in this project, our web app uses the Web Bluetooth API.

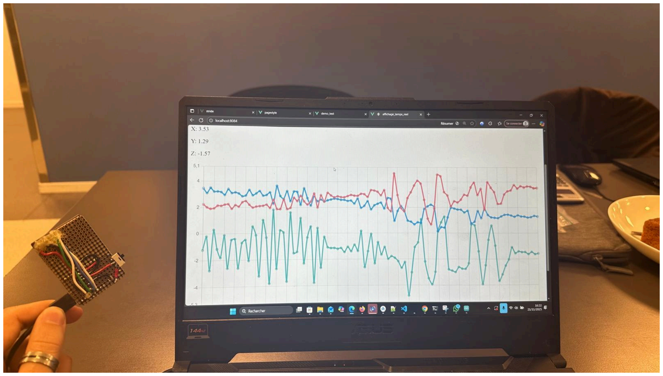
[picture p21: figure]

Figure 6.23 : Independence between the card(BLE client) and the computer (BLE server)

UUIDs and Security Context
Each BLE service and characteristic is identified by a UUID, allowing the client to locate and access specific data. During connection, the browser queries these UUIDs to determine available sensor characteristics. For security reasons, browsers only allow BLE access from secure HTTPS contexts or localhost. This prevents untrusted websites from scanning or interacting with nearby Bluetooth devices. Once connected, data is received as binary packets, decoded and displayed or processed in real time. For more details, these resources can be useful : [25] and [26].

## 6.5. UserInterface design and application development

The user interface (UI) plays a crucial part in the overall user experience, as it is the first thing a user interacts with. During this project, attention was given to designing an interface that is both intuitive and user-friendly.

Choosing code :
For this project, we had many options to choose from, but as a team with limited coding experience, we decided to use Nuxt 4 as the foundation for our website/web app. Combining Nuxt 4 with HTML and JavaScript was challenging at first, but it proved to be well worth the effort. Nuxt provides a clean structure, automatic routing, and useful tools that make the development process easier and faster. Since Nuxt is built on Vue, our team can write template-style code that feels like enhanced HTML while still benefiting from reactive JavaScript and modern web features.

By taking these features into account, I decided to develop a website first rather than an app. This allowed us to clearly demonstrate the core functionality and the intended use of the product. After this, we were hoping to configure the code from the website into an app. This turned out to be a very difficult task. Unfortunately, it was something that we as a project group weren’t able to do with our skillset.

Since this was a completely new experience for the entire team, making a website offered greater stability and provided more opportunities to work on the project.

Implementation

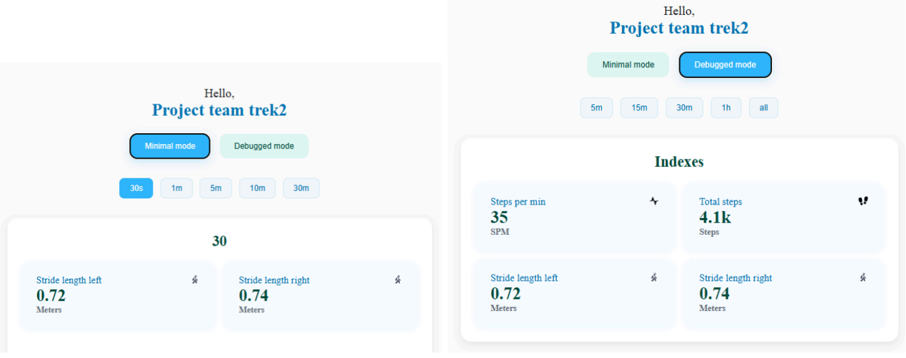
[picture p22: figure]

Figure 6.24: UI design

In the implementation (as shown in Visual Studio Code), we integrated functionality that allows the user to switch between Minimal Mode and Debugged Mode. Each mode provides access to five different time frames, enabling users to observe patient activity over different intervals. These time frames display valuable insights such as the number of steps taken and any deviations in movement patterns.

Real-Time Visualization
A local web application was developed to display real-time data, providing an overview of the patient's performance. The User Interface offers both the minimal and debugged modes, allowing users to toggle between simplified and extensive views as needed (see figures above).

Minimal Mode
The Minimal Mode focuses on essential metrics, presenting only the most important information for quick assessment. Displayed indexes include:
- Stride length of the left and right legs.
- A parabolic graph illustrating the deviation between the left and right leg.

This mode enables users to instantly identify differences or imbalances between the patient’s left and right strides, ensuring fast interpretation without unnecessary data clutter.

Debugged Mode
The Debugged Mode provides an expanded view of patient performance, offering a deeper insight into movement dynamics. Displayed indexes include:
- Steps per minute
- Total steps
- Step deviation (left and right)

These indicators are numerical indicators and are being shown in two graphs:
1. A deviation graph, visualising the differences between the left and right leg.
2. A cumulative steps graph, showing the total number of steps taken by the patient over time.
This mode supports in-depth analysis, enabling healthcare professionals to monitor progress and identify potential gait irregularities more effectively.

## 6.6. Integration and system validation

The integration involves assembling the case with the Nicla Sense and the battery. The battery is secured in the bottom part of the case, and the PCB Board with all its components is positioned in the designated location on top. The upper part of the case is then screwed onto the bottom part, holding all components firmly in place. Afterwards, it is verified that all connectors are correctly positioned and the strap is attached, resulting in a fully functional overall system.
The system validation then checks whether the assembled prototype meets the planned requirements. This includes ensuring that the case fits properly on the foot, the battery supplies power correctly, the control elements such as the Bluetooth button and the On/Off switch function properly, and that the measurements from the sensors operate as intended.

Figure 6.25 : Integration of all the components in the case

## 7. Conclusion

## 7.1. Project conclusions and key findings

The development of Trek 2.0 has successfully transformed the previous prototype into a more capable, compact and user-friendly gait monitoring system. Whilst building on the foundation left by the previous group, our team implemented significant improvements across hardware, firmware, signal processing, wireless communication and user interface design.

The custom PCB and housing allowed us to reduce the total device size. Improving the power efficiency and reliability of the product ensured that we have created a gait monitoring system that supports recovery and daily function.

The development of a local website provided a medium for visualisation, which shows the time window analysis and mode selection.

With these improvements, Trek 2.0 is now presented as a complete and adaptable solution for gait monitoring, capable of processing patient information in real time according to user needs.

In the future, this bracelet could serve as an effective tool for tracking patient progress, allowing healthcare professionals to easily interpret the data displayed on the user interface and tailor care accordingly.

## 7.2. Skills acquired

Chethan :
During the EPS project, I applied my existing skills in PCB design and troubleshooting, prototype testing, and resource planning, ensuring the project stayed on track despite hardware issues. I also used my experience in team coordination, separating hardware and programming tasks to improve efficiency.

Jeya :
I learned a lot during this project, both in terms of management and technical skills. I worked on signal processing at a higher level than in my previous projects, facing significant hardware constraints, which allowed me to be fully immersed in the work of an embedded systems engineer. It also helped me understand and apply new algorithms, such as the Kalman filter, and see firsthand how they contribute in a real system.

Thomas :
During my engineering studies, I primarily focused on mechanical and electrical fields. However, during this EPS project, I was able to develop skills in a field that didn’t initially attract me: computer science. Starting with work on wireless communication, I learned more about Bluetooth communication, a technology that surrounds our daily lives. Additionally, I enhanced my coding skills by developing the user interface for the website we aimed to create. I discovered a real passion for these tasks and found genuine satisfaction in accomplishing them.

Michael :
During the project, I further enhanced my skills in CAD design and 3D printing, especially through the practical creation of a functional prototype. I was responsible for the mechanical design, through which I learned how to coordinate decisions within a team. Taking responsibility for my own area, from design to the manufacturing of the prototype in an international team, was another key learning experience. Additionally, I was able to improve my English skills.

Luke :
During this project, I developed new skills that will support my future career as a mechanical engineer. I began with basic coding, which eventually grew into building a fully functioning website. This is something I never would have expected at the start of the project.
In addition to technical skills, I also improved my ability to work effectively in a team. Even when things didn’t go my way, I stayed communicative and helped divide the workload to benefit the project. By applying the methods taught in class, our group gradually became a more efficient and cooperative team.

## 7.3. Reflections and overall experience

Chethan :
While the PCBs did work in the end and matched our use case, a smaller, thinner application would have better met the project's needs. In an ideal world, the programmer for the Arduino would be separate, and only the Arduino's CPU, RGB LED, and necessary passive components would be on the board.

The PCB itself, like any V1, can be improved. In a subsequent version, the following changes should be made.
- Flip the JST connector 180 degrees
- FLIP the MicroSD card reader 180 degrees or remove capacitors / resistors, as they are in the way of inserting an MicroSD card
- Remove R5, this resistor ties the TS to the OUT pin on the LDO for the charging circuit, causing the charger not to function correctly
- issue with button, needs to be rotated 90 degrees, or GND should be on the opposite pin These errors resulted in a few wasted boards and Nicla’s being unusable ( the pins on the Arduino Nicla board were soldered to what was thought as a completed board, as while the initial tests were passed, further errors were found upon a second validation ). We would also recommend a future group attach pin headers ( assuming they do not make a custom Arduino ) only to the PCB and not the Nicla during testing.

In addition, we would recommend designing and purchasing boards early on in the project, although we recognize this is dictated by other project dependencies. Assuming purchasing custom boards is not feasible, we would recommend purchasing at least additional programming boards and PCBs. Again, both in advance if possible, as Arduinos can be purchased at the very beginning of a project, and more duplicates of PCBs give the project additional slack in case something goes wrong. Purchasing additional PCBs allowed for the project's success despite testing and validation errors ( ideally, these errors don’t happen at all, but the additional PCBS kept our group from having an unusable prototype ).

Jeya :
C'était une nouvelle expérience, la première fois que je travaillais avec des personnes que je ne connaissais pas, et encore plus avec des nationalités différentes. il y a eu des hauts et des bas, mais j’ai été content de voir une équipe soudée. j’ai aussi beaucoup appris sur les autres, leurs cultures, leurs façons de travailler et leurs connaissances.

Thomas :
During this project, I was able to discover new ways of working by interacting daily with people from different cultures. At first, it was quite unsettling because I had been taught to work in a certain way throughout my schooling. But by embracing these new working methods, I was able to open myself up more to the world around me, improving both my listening skills and my ability to learn.

Michael :
The work on the project was characterized by close collaboration within the team. Since the housing had to be precisely matched to the internal components, continuous coordination was necessary with the team members responsible for electronics and sensor technology. Many design decisions could therefore only be made once certain technical details had been determined. A challenge was that we, as exchange students, were not always available at the same time. Due to absences, tasks sometimes had to be restructured or rescheduled to avoid further delays in the project. Communication of technical terms was challenging, as it was conducted in English, which was a foreign language for most team members. This allowed us, as a team, to make continuous progress and move closer to our goal of creating a functional prototype.

Luke :
I entered the project with a background in mechanical engineering, a field heavily focused on calculations, design, and understanding how a product behaves or appears.However, my primary responsibility in this project was working on the user interface, an area completely new to me. This made the project both challenging and exciting.I spent a significant amount of time researching where to begin and eventually started working with Nuxt 4 and Vue to create a smooth and pleasant user experience.

Despite the excitement. I faced personal challenges. My health occasionally forced me to step back, and I made sure to communicate openly with the group whenever this happened. Near the end of the project, I was unfortunately involved in a car accident, which required me to step away for several weeks. This was difficult, but I am very grateful that Thomas stepped in and supported the team during that time.Spending long hours behind a screen became particularly tough, which may be reflected in my (latest) work.

In the end, everything came together. In my honest and professional opinion, I highly recommend participating in a project like this with a diverse group of international students, just as we did. It was a valuable and rewarding experience.

## 8. References

[1] Werner, M., Macke, C., Gogol, M., Krettek, C., & Liodakis, E. (2021). Differences in hip fracture care in Europe: a systematic review of recent annual reports of hip fracture registries. Epub October 8, 2021. https://pubmed.ncbi.nlm.nih.gov/34623474/
[2] Engdal, M., Taraldsen, K., Jansen, C.-P., Peter, R. S., Vereijken, B., Becker, C., Helbostad, J. L., & Klenk, J. (2024). Real-world mobility recovery after hip fracture: secondary analyses of digital mobility outcomes from four randomized controlled trials. Ageing, published October 28, 2024. https://academic.oup.com/ageing/article/53/10/afae234/7848285?login
[3] Steihaug, O. M., Gjesdal, C. G., Bogen, B., Kristoffersen, M. H., Lien, G., & Ranhoff, A. H. (2017). Sarcopenia in patients with hip fracture: A multicenter cross-sectional study. https://pubmed.ncbi.nlm.nih.gov/
[4] Pol, M. C., ter Riet, G., van Hartingsveldt, M., Kröse, B., & Buurman, B. M. (2019). Effectiveness of sensor monitoring in a rehabilitation programme for older patients after hip fracture: a three-arm stepped wedge randomised trial. https://ouci.dntb.gov.ua/en/works
[5] MbientLab. (n.d.). MMRL – MetaMotion RL. https://mbientlab.com/store/metamotionrl/
[6] Movella. (n.d.). Xsens MVN Awinda. https://www.movella.com/motion-capture/xsens-mvn-awinda
[7] Wikipedia. (n.d.). Gait (human). https://en.wikipedia.org/wiki/Gait_%28human%
[8] Bytyçi, I., & Henein, M. Y. (2021). Stride length predicts adverse clinical events in older adults: A systematic review and meta-analysis. Journal of Clinical Medicine, 10(12), 2670. https://www.mdpi.com/2077-0383/10/12/2670
[9] Wang, S., & Bhatt, T. (2022). Gait kinematics and asymmetries affecting fall risk in people with chronic stroke: A retrospective study. MDPI Geriatrics, 2(3), 35. https://www.mdpi.com/2673-7078/2/3/35
[10] Laidig, D., Jocham, A. J., Guggenberger, B., Adamer, K., Fischer, M., & Seel, T. (2021). Calibration-free gait assessment by foot-worn inertial sensors. Frontiers in Digital Health. https://www.frontiersin.org/journals/digital-health/articles/10.3389/fdgth.2021.736418/full
[11] Han, S. H., Kim, C. O., Kim, K. J., Jeon, J., Chang, H., Kim, E. S., & Park, H. (2019). Quantitative analysis of the bilateral coordination and gait asymmetry using inertial measurement unit-based gait analysis. PLOS One. https://journals.plos.org/plosone/article?id=10.1371%2Fjournal.pone.0222913
[12] Küderle, A., Roth, N., Zlatanovic, J., Zrenner, M., Eskofier, B., & Kluge, F. (2022). The placement of foot-mounted IMU sensors does affect the accuracy of spatial parameters during regular walking. PLOS ONE. https://journals.plos.org/plosone/article?id=10.1371/journal.pone.0269567

[13] Panebianco, G. P., Bisi, M. C., Stagni, R., & Fantozzi, S. (2018). Analysis of the performance of 17 algorithms from a systematic review: Influence of sensor position, analysed variable and computational approach in gait timing estimation from IMU measurements. Gait & Posture. https://www.sciencedirect.com/science/article/abs/pii/S0966636218304004
[14] Błażkiewicz, M., Wiszomirska, I., & Wit, A. (2014). Comparison of four methods of calculating the symmetry of spatial-temporal parameters of gait. Acta of Bioengineering and Biomechanics.
[15] Gimmon, Y., Rashad, H., Kurz, I., Plotnik, M., Riemer, R., Debi, R., Shapiro, A., & Melzer, I. (2018). Gait coordination deteriorates in independent old-old adults. Journal of Aging and Physical Activity.
https://doi.org/10.1123/japa.2017-0120.https://in.bgu.ac.il/engn/iem/BRL/Documents/Publications/Gait%20Coordination%20Deterior ates%20in%20Independent%20Old-Old%20Adults.pdf (https://in.bgu.ac.il/engn/iem/BRL/Documents/Publications/Gait%20Coordination%20Deteriorates%20in%20Independent%20Old-Old%20Adults.pdf)
[16] Didouh, A., Marquardt, R., Renou, K., Trewhella, M., & Weidner, J. (2024). Musculoskeletal Monitoring System. EPS4000: European Project Semester. Tom Muir and Tengel Aas Sandtro. November 25, 2024.
[17] PubMed Central. (s.d.). Article. PMC. https://pmc.ncbi.nlm.nih.gov/articles/PMC12355143/

[18]Eurocircuits.(s.d.).EC Login. Eurocircuits. https://be.eurocircuits.com/shop/ECLogin.aspx

[19] All3DP. (s.d.). PLA vs ABS vs PETG: The Main Differences. All3DP. https://all3dp.com/3d-design/pla-vs-abs-vs-petg-the-main-differences
[20] Bosch Sensortec. (s.d.). BHI260AP Datasheet. Bosch Sensortec. https://www.bosch-sensortec.com/media/boschsensortec/downloads/datasheets/bst-bhi260a p-ds000.pdf (https://www.bosch-sensortec.com/media/boschsensortec/downloads/datasheets/bst-bhi260ap-ds000.pdf)
[21] CNX Software. (2021, January 5). BHI260AP is an AI smart sensor with built-in IMU by Bosch Sensortec. CNX Software. https://www.cnx-software.com/2021/01/05/bhi260ap-ai-smart-sensor-with-built-in-imu-by-bosch-sensortec/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 of%201.8%20V%20with%20a%20standby%20current%20value%20of%208%C2%B5A%2C %20hence%20the%20power%20consumption%20is%20only%200.014%20mW%20in%20st andby%20mode (https://www.cnx-software.com/2021/01/05/bhi260ap-ai-smart-sensor-with-built-in-imu-by-bosch-sensortec/)
[22] Arduino. (s.d.). Sensors IDs. Arduino Docs. https://docs.arduino.cc/tutorials/nicla-sense-me/cheat-sheet/#:~:text=from%20the%20sensor s.-,Sensor%20IDs,-The%20IDs%20to (https://docs.arduino.cc/tutorials/nicla-sense-me/cheat-sheet/)
[23] | Epomedicine. | (2014, | May | 26). | Examination | of | Gait. | Epomedicine.
https://epomedicine.com/clinical-medicine/physical-examination-gait/

[24] Castermans, T., Duvinage, M., Cheron, G., & Dutoit, T. (2013). Towards Effective Non-Invasive Brain-Computer Interfaces Dedicated to Gait Rehabilitation Systems. Brain Sciences, 4(1), 1. https://www.mdpi.com/2076-3425/4/1/1
ResearchGate version:
https://www.researchgate.net/publication/259632493_Towards_Effective_Non-Invasive_Brain-Computer_Interfaces_Dedicated_to_Gait_Rehabilitation_Systems (https://www.researchgate.net/publication/259632493_Towards_Effective_Non-Invasive_Brain-Computer_Interfaces_Dedicated_to_Gait_Rehabilitation_Systems)
[25] | Web | Bluetooth | Community | Group. | (n.d.). | Web | Bluetooth.
https://webbluetoothcg.github.io/web-bluetooth
[26] Mozilla Developer Network. (n.d.). Web Bluetooth API. https://developer.mozilla.org/en-US/docs/Web/API/Web_Bluetooth_API

## 9. Appendix

The AI language model ChatGPT was used as a supportive tool during the preparation of this report. Its assistance was limited to improving phrasing, enhancing clarity, and correcting grammar and language usage. All technical content, analysis, and conclusions presented in this report were generated by the authors, with ChatGPT serving only as a writing aid and not influencing the scientific or technical work.

## Power Calculations

Assumptions
Operation: 16 hr active + 8 hr sleep Battery: Lithium Ion batter, 3.7 V

Active
IMU (active): 0.50 mA
BLE (nRF52 radio): peaks ≈5.3 mA TX / 5.4 mA RX;
on-air 3 ms per 100 ms interval (≈1.5 ms TX + 1.5 ms RX) BLE Avg = (5.3 * 1.5 + 5.4 * 1.5 ) / = 0.1605 mA
microSD (batched every 1 s during active):
Peak Current; 100 mA | Idle Current: 0.2 mA
per-record write time; 3 ms overhead per burst; 10 ms | 10 records/burst
Burst Time = 10(3 + 10 = 40ms, or 0.04 s
AVG Current = 0.2 + (100-0.2) *0.04 = 4.192 mA
Duty during active = (40/1000=0.04)

Sleep
Nicla standby 0.46 mA, SD idle 0.20 mA, Net 0.66 mA

Per-day mAh
IMU: 0.5 mA * 16 hr = 8 mAh
BLE: 0.1605 mA * 16 hr = 2.68 mAh
SD: 4.192 mA * 16 hr = 67.072 mAh
Sleep: 0.66 mA * 8 hr = 5.28 mAh
Total: (8 + 2.68 + 67.072 + 5.28 ) mAh = 82.82 mAh
.Total mWh = Battery voltage * Total mAh = 3.7v * 82.92 = 306.8 mWH

The vast majority of the power consumption is from the SD card at roughly 81% of the power cost. This is non-negotiable for our client, but alternative solutions such as cloud storage or increased processor cache size to decrease microSD access rates are recommended.

## MicroSD Card Memory Calculation

Is the SD card's memory capacity a limiter? No.

The SD card we have is 32 GB. Assuming we send 5 floats ( 3 for sensor data, 1 for timestamp, and 1 for ID ) every 100ms ( for our 10 Hz Sampling rate ), we get:

5 floats per sample = 20 Bytes / sample
10 samples per second = 200 Bytes per second
200 Bytes per second 60 60 24 = 17.28 MB / Day

The SD Card has 32,000 Mb. 32000 /17.28 = 18,151 days or more than 5 years of storage

## PCB Images

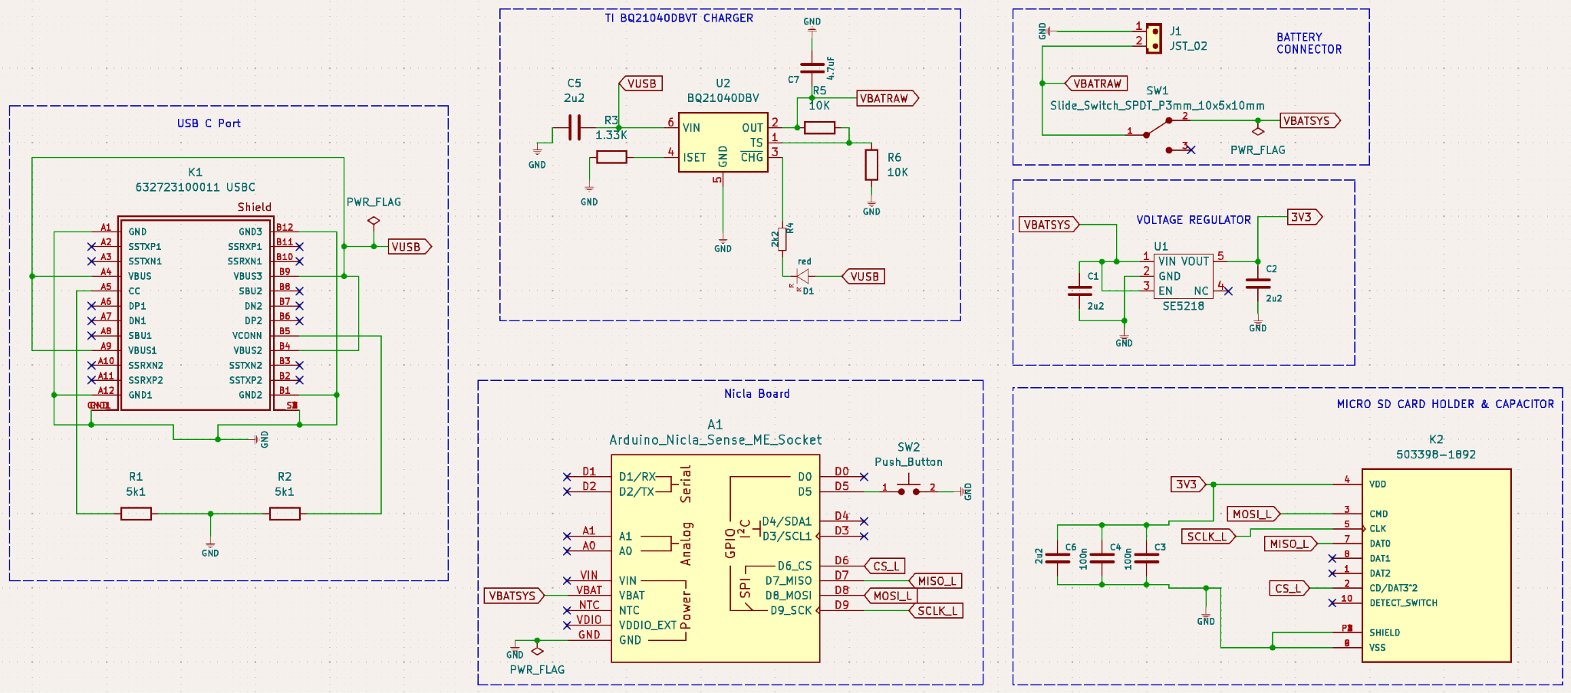
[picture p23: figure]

Printed Circuit Board Schematic, Kicad

Printed Circuit Board Layout, Kicad

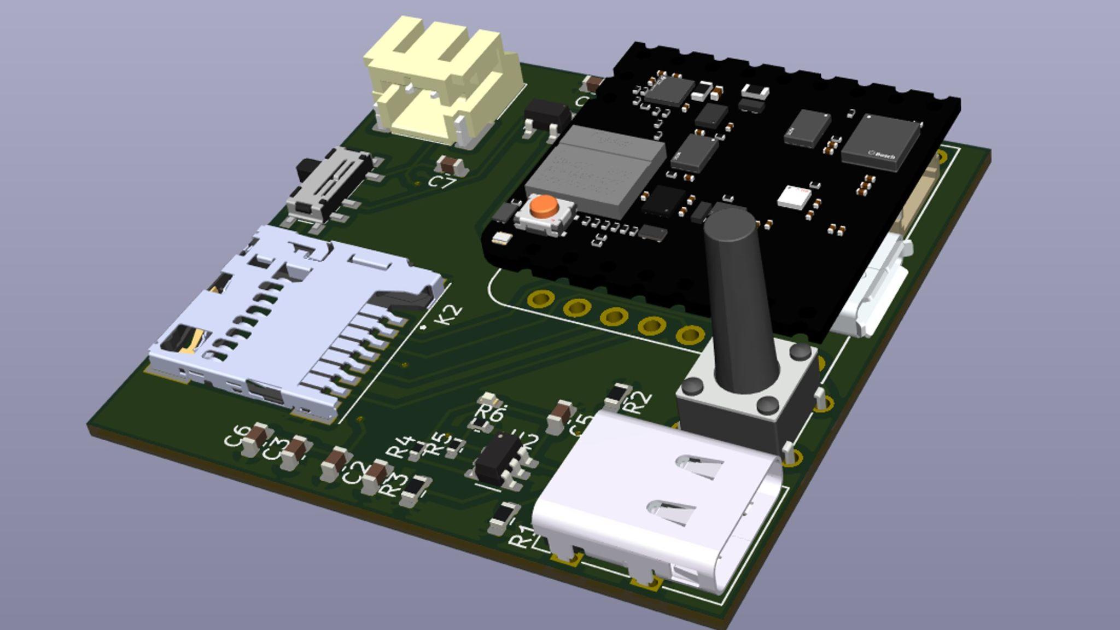
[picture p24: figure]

Printed Circuit Board 3D Model, Kicad

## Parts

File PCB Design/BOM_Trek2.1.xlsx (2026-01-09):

Designators | Qty | Value | Description | Manufacturer | MPN | Package | Notes / DNP
U2 | 1 | BQ21040 | Li-ion 1-cell linear charger, SOT-23-6 | Texas Instruments | BQ21040DBVT | SOT-23-6 | TS mid-bias: R5/R6 10 k
U1 | 1 | 3.3 V, 600 mA | LDO Regulator, 3.3 V fixed, SOT-23-5 | SEASemi (or alt.) | SE5218-33 (alt: AP2112K-3.3) | SOT-23-5 | Input/Output caps 2.2 µF
K1 | 1 | USB-C Receptacle | 24-pin right-angle receptacle, mixed TH/SMD | Würth Elektronik | 632723100011 | Custom (mixed) | TH shell lugs to GND; hand-solder if no THT assembly
K2 | 1 | microSD Socket | Hinged microSD holder | Molex | 503398-1892 | Molex microSD | Place decouplers close
J1 | 1 | 2-pin, 2.0 mm | JST-PH battery header, side-entry, SMD | JST | BM02B-PH-SM4-TB(LF)(SN) | SMD | Battery connector
SW1 | 1 | SPDT | Slide switch, 3 mm pitch, ~10×5×10 mm | Generic / C&K | (e.g.) JS102011SAQN | TH | Battery isolate selector
SW2 | 1 | Momentary | THT pushbutton, 9.5 mm actuator | Karson | 970-001-03-00 | TH | Hand-solder if no THT assembly
D1 | 1 | Red LED | Red indicator LED | Any | 0402 red (e.g. LTST-C190KRKT) | 402 | Series R4 = 2.2 k to VUSB
R1, R2 | 2 | 5.1 k | USB-C CC pull-downs (to GND) | Any | 1% | 402 | For Sink-only
R3 | 1 | 1.33 k | BQ21040 ISET (charge current set) | Any | 1% | 402 | Sets I_CHG (~1 A per TI table)
R4 | 1 | 2.2 k | LED current-limit (D1) | Any | 1% | 402 | Red LED to VUSB
R5, R6 | 2 | 10 k | TS bias divider (midpoint ≈ VBAT/2) | Any | 1% | 402 | For thermistor bypass mode
C1 | 1 | 2.2 µF / 10 V | VIN (VUSB) input cap (charger) | Any | X5R/X7R | 603 | Close to U2 VIN
C7 | 1 | 4.7 µF / 6.3–10 V | VBAT output/rail cap (charger) | Any | X5R/X7R | 603 | Close to U2 OUT/VBAT
C2 | 1 | 2.2 µF / 10 V | LDO output (3V3) | Any | X5R/X7R | 603 | As per U1 datasheet
C5 | 1 | 2.2 µF / 10 V | LDO input (VCC/VBATSYS) | Any | X5R/X7R | 603 | As per U1 datasheet
C3, C4, C6 | 3 | 0.1 µF | Decouplers (microSD / local) | Any | X7R | 402 | Place close to K2 pins
FIDs (Top) | 3 | — | Global fiducials, 0.5 mm Cu, 1.5 mm mask | — | — | SMD pad | No paste; no net
A1 | 1 | Arduino Nicla | Castellated socket/footprint only | Arduino | Nicla Sense ME | Castellated | DNP (do not assemble)

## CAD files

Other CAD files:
3D model/Case 1 top.ipt
3D model/Case 1.ipt
3D model/Case 2 top.ipt
3D model/Case 2.ipt

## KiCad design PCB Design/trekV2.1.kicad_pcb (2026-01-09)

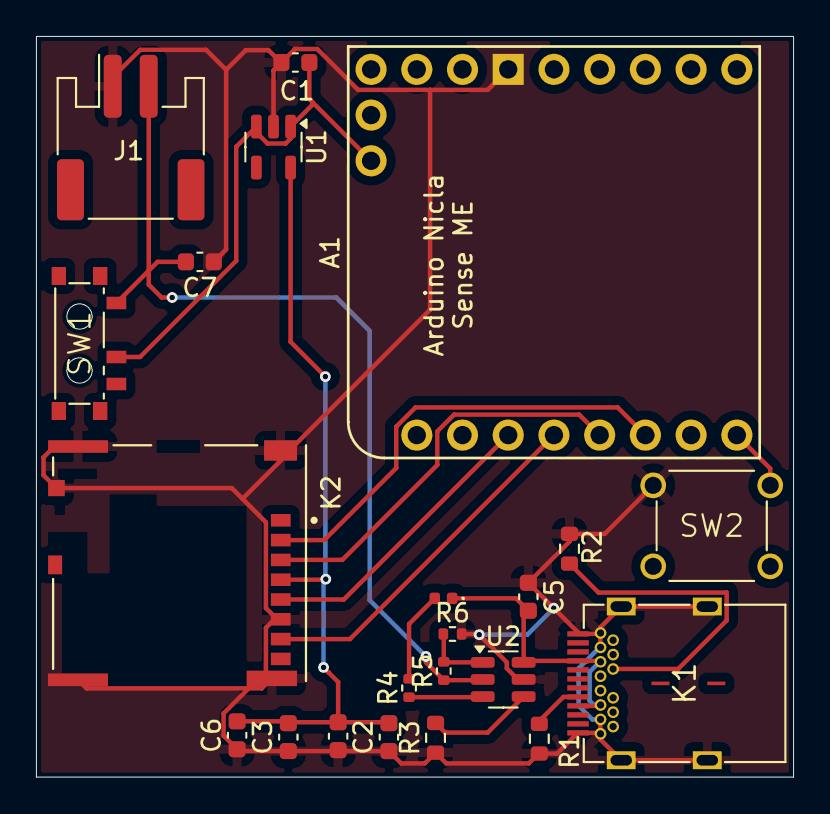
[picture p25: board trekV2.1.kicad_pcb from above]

Board: 2 copper layers, 42.1 x 41.1 mm, 22 parts (0 on the bottom side), 16 nets.

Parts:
A1: Arduino_Nicla_Sense_ME_Socket; Arduino_Nicla_Voice_Socket
C1, C2, C5, C6: 2u2; C_0603_1608Metric
C3, C4: 100n; C_0603_1608Metric
C7: 4.7uF; C_0603_1608Metric
D1: red; LED_0402_1005Metric
J1: JST_02; JST_PH_S2B-PH-SM4-TB_1x02-1MP_P2.00mm_Horizontal
K1: 632723100011 USBC; CONN_WURTH_632723100011
K2: 503398-1892; MOLEX_503398-1892
R1, R2: 5k1; R_0603_1608Metric
R3: 1.33K; R_0603_1608Metric
R4: 2k2; R_0402_1005Metric
R5, R6: 10K; R_0402_1005Metric
SW1: Slide_Switch_SPDT_P3mm_10x5x10mm; SW_WURTH_450404015514
SW2: Push_Button; SW_KARSON_970-001-03-00
U1: SE5218; SOT-23-5
U2: BQ21040DBV; SOT-23-6

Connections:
3V3: C2.2, C3.2, C4.2, C6.2, K2.4 (VDD), U1.5 (VOUT)
CS_L: A1.D6 (D6_CS), K2.2 (CD/DAT3^2)
GND: A1.GND, C1.1, C2.1, C3.1, C4.1, C5.1, C6.1, C7.1, J1.1, K1.A1 (GND), K1.A12 (GND1), K1.B1 (GND2), K1.B12 (GND3), K1.GND, K1.GND1, K1.S1, K1.S2, K1.S3, K1.S4, K2.6 (VSS), K2.9 (VSS), K2.P1 (SHIELD), K2.P2 (SHIELD), K2.P3 (SHIELD), K2.P4 (SHIELD), R1.2, R2.2, R3.1, R6.2, SW2.2, U1.2 (GND), U2.5 (GND)
MISO_L: A1.D7 (D7_MISO), K2.7 (DAT0)
MOSI_L: A1.D8 (D8_MOSI), K2.3 (CMD)
unnamed: A1.D5, SW2.1
unnamed: D1.2 (K), R4.2
unnamed: K1.A5 (CC), R1.1
unnamed: K1.B5 (VCONN), R2.1
unnamed: R3.2, U2.4 (ISET)
unnamed: R5.2, R6.1, U2.1 (TS)
unnamed: R4.1, U2.3 (~CHG)
SCLK_L: A1.D9 (D9_SCK), K2.5 (CLK)
VBATRAW: C7.2, J1.2, R5.1, SW1.1, U2.2 (OUT)
VBATSYS: A1.VBAT, C1.2, SW1.2, U1.1 (VIN), U1.3 (EN)
VUSB: C5.2, D1.1 (A), K1.A4 (VBUS), K1.A9 (VBUS1), K1.B4 (VBUS2), K1.B9 (VBUS3), U2.6 (VIN)

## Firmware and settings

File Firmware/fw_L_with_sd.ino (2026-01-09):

#include <Arduino_BHY2.h>    // Library to access the Nicla Sense ME sensors
#include <ArduinoBLE.h>      // Library to handle Bluetooth Low Energy (BLE) communication
#include "Nicla_System.h"    // Provides system-level functions for Nicla boards
#include <math.h>            // To use math functions
#include <SD.h>
#include <SPI.h>

// --- Define SensorsID --- 
SensorXYZ linearAcc(SENSOR_ID_LACC);
SensorXYZ gyroscope(SENSOR_ID_GYRO);

// --- BLE parameters ---
const char* bleDeviceName = "NiclaBLE1";
const int BLE_FLOAT_COUNT_TX = 2;
const unsigned long bleWaitDuration = 20000; //20sec
const unsigned long bleReWaitDuration = 200000; //200sec

// --- Define a custom BLE service and characteristic --- 
const int bufferSize = BLE_FLOAT_COUNT_TX * 4;
BLEService imuService("12345678-1234-1234-1234-123456781234");
BLECharacteristic imuCharacteristic("12345679-1234-1234-1234-123456781234", BLERead | BLENotify, bufferSize);
BLECharacteristic cmdCharacteristic("12345671-1234-1234-1234-123456781234", BLEWrite | BLEWriteWithoutResponse, 1);

// --- UI mode ---
enum UIMode : uint8_t { MINIMAL = 0, DEBUG = 1, RESET = 2 };
bool bleConnected = false;
UIMode ui_mode = MINIMAL;; // 0 = minimal mode, 1 = debug, 2 = reset
unsigned long connectStartTime = 0;
bool reconnecting = false;
bool resetFinished = false;
bool sdAlreadySent = false;

// --- Computation variables ---
static unsigned long prevTime = 0;
float accScale = 1/4096.0;
float gyroScale = 2.0 * 3.14159265 / 360.0 * (2000.0 / 32768.0);
const float g = 9.81;

int count = 0;
float prevAccMag = 0.0;
float emaAlpha = 0.2;
float emaDerivAlpha = 0.3;
float emaAccMag = 0.0;       // EMA of acceleration magnitude
float emaDeriv = 0.0;        // EMA of derivative
float accMagTol = 0.1;
float derivMagTol = 2.0;

bool prevSwingState = false;
bool startCalc = false;

float minGz = 0.0;
int idMinGz = 0;
float prevFiltAy = 0.0;
float vy = 0.0;
float py = 0.0;
float strideLength = -1.0;

// --- SD parameters ---
#define PIN_SD_CS 10  // adapte selon ta carte
String filePath = "/root/trek_bracelet/data.txt";
bool sdOk = false;

void setup() {
  Serial.begin(115200);
  while (!Serial);

  //
  nicla::begin();
  nicla::leds.begin();
  nicla::leds.setColor(green);

  // Init SD
  if (!SD.begin(PIN_SD_CS)) {
    Serial.println("SD.begin FAILED, continuing without SD");
    sdOk = false;
  } else {
    Serial.println("SD OK");
    sdOk = true;
  }

  // Initialize the sensor hub (BHI260) and sensors
  BHY2.begin(NICLA_STANDALONE);
  linearAcc.begin();
  gyroscope.begin();

  // Init BLE
  if (!BLE.begin()) {
    Serial.println(" BLE init failed!");
  }

  // Configure BLE settings
  BLE.setLocalName(bleDeviceName);
  BLE.setAdvertisedService(imuService);
  imuService.addCharacteristic(imuCharacteristic);
  imuService.addCharacteristic(cmdCharacteristic);
  BLE.addService(imuService);

  // Set event handler for UI mode command
  cmdCharacteristic.setEventHandler(BLEWritten, receiveUIModeCommand);

  BLE.advertise();
  Serial.println("Advertising...");

  // Independent BLE check phase
  connectStartTime = millis();
  while (millis() - connectStartTime < bleWaitDuration) {
    BLEDevice central = BLE.central();
    if (central) {
      Serial.println("Central connected during initial phase!");
      bleConnected = true;
      nicla::leds.setColor(blue);
      break; // connexion établie, sortir de la boucle d'attente
    }
  }

  if (!bleConnected) {
    BLE.stopAdvertise();
    nicla::leds.setColor(red);
    Serial.println("No connection after " + String(bleWaitDuration / 1000) + " sec, offline mode");
  }

  Serial.println("Starting main loop...");
}

void loop() {
  BLEDevice central = BLE.central();
  if (central && central.connected()) {
    if(!bleConnected) {
      Serial.println("Reconnected..");
      nicla::leds.setColor(blue);
      bleConnected = true;
      reconnecting = false;

      count = 0;
      initParams();
    }
  } else {
    if(bleConnected) {
      Serial.println("Disconnected..");
      nicla::leds.setColor(red);
      bleConnected = false;
      ui_mode = MINIMAL;

      // Start reconnection attempt
      reconnecting = true;
      connectStartTime = millis();
      BLE.advertise();
    }
  }

  // Stop reconnect phase if timeout exceeded
  if (reconnecting && (millis() - connectStartTime >= bleReWaitDuration)) {
    reconnecting = false;
    BLE.stopAdvertise();
    Serial.println("Reconnect timeout, continuing offline");
  }

  // Handle tasks depending on UI mode
  switch (ui_mode) {
    case MINIMAL: {
      computeStrideLength();
      delay(20);
      break;
    }

    case DEBUG:
      // debug mode tasks
      Serial.println("debug");
      nicla::leds.setColor(white);
      if(!sdAlreadySent) {
        sendSD();
      }
      break;

    case RESET:
      // reset mode tasks
      Serial.println("reset");
      if (!resetFinished) {
        clearSD();
      }
      nicla::leds.setColor(red);
      delay(100);
      nicla::leds.setColor(off);
      break;
  }
  
}

// --- UI mode handler ---
void receiveUIModeCommand(BLEDevice central, BLECharacteristic characteristic) {
  if (characteristic.valueLength() > 0) {
    ui_mode = static_cast<UIMode>(*(characteristic.value())); // read single byte and cast to enum
    Serial.print("UI mode updated to: ");
    Serial.println(ui_mode);

    // Update LED color once when UI mode changes via BLE command
    switch (ui_mode) {
      case MINIMAL: nicla::leds.setColor(blue); break;
      case DEBUG: nicla::leds.setColor(white); break;
    }
  }
}

// --- BLE send ---
void sendMessage(float x, float y) {
  uint8_t data[bufferSize];
  memcpy(data, &x, 4);
  memcpy(data + 4, &y, 4);
  imuCharacteristic.writeValue(data, bufferSize);
}

// --- Compute stride ---
void computeStrideLength() {
  BHY2.update();

  unsigned long currentTime = millis();
  float deltaTime = (currentTime - prevTime) / 1000.0; // Delta time in seconds
  prevTime = currentTime;

  float ax = linearAcc.x() * accScale;
  float ay = linearAcc.y() * accScale;
  float gz = gyroscope.z() * gyroScale;

  //
  float accMag = sqrt(ax * ax + ay * ay);
  float derivMag = (accMag - prevAccMag) / deltaTime;
  prevAccMag = accMag;

  // EMA smoothig
  emaAccMag = emaAlpha * accMag + (1 - emaAlpha) * emaAccMag;
  emaDeriv = emaDerivAlpha * derivMag + (1 - emaDerivAlpha) * emaDeriv;

  //
  bool magNearRef = abs(emaAccMag) < accMagTol;
  bool magSlow = abs(emaDeriv) < derivMagTol;

  bool swingState = !(magNearRef && magSlow);

  if (!prevSwingState && swingState) {
    count = 0;
    startCalc = true;

    minGz = gz;
    idMinGz = 0;
    strideLength = -1.0;
  }

  if (startCalc){
    float filtAy = ay*g;
    vy += ((filtAy + prevFiltAy) / 2.0) * deltaTime;
    py += vy*deltaTime;
    prevFiltAy = filtAy;

    if (gz<minGz) {
      minGz = gz;
      idMinGz = count;
      strideLength = py;
    }
  }
  
  if (prevSwingState && !swingState) {
    startCalc = false;
    if(strideLength > 0.001){
      strideLength = strideLength*100;
      strideLength = (strideLength + 16.4)/0.682;
      if (bleConnected) {
        sendMessage(strideLength, ay);
      }
      writeSD(strideLength, ay)
    }
    //
    initParams();
  }

  //à la fin
  prevSwingState = swingState;
  count += 1;
} 

void initParams() {
  prevFiltAy = 0.0; 
  vy = 0.0;
  py = 0.0;
}

// --- SD functions ---
void writeSD(float val1, float val2) {
  if (!sdOk) return;
  last_id++;
  File f = SD.open(filePath, FILE_WRITE);
  if (!f) { Serial.println("Erreur ouverture fichier pour écriture"); return; }
  f.print(val1,4); f.print(","); f.println(val2,4);
  f.close();
  Serial.println("Données écrites dans SD");
  resetFinished = false;
}

void sendSD() {
  if (!sdOk || !SD.exists(filePath)) { Serial.println("Fichier inexistant ou SD KO"); return; }
  File f = SD.open(filePath, FILE_READ);
  if (!f) { Serial.println("Erreur ouverture fichier pour lecture"); return; }
  
  while (f.available()) {
    String line = f.readStringUntil('\n');
    if (line.length() == 0) continue;

    int comma = line.indexOf(',');
    if (comma < 0) continue;

    float val1 = line.substring(0, comma).toFloat();
    float val2 = line.substring(comma + 1).toFloat();

    sendMessage(val1, val2);
    delay(20);
  }

  f.close();
  sdAlreadySent = true;
}

void clearSD() {
  if (!sdOk) return;
  File f = SD.open(filePath, FILE_WRITE);
  if (f) f.close();
  SD.remove(filePath);
  Serial.println("Fichier vidé");
  resetFinished = true;
}
